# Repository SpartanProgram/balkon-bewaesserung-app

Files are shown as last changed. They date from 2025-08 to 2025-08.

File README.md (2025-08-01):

# 🌱 Balkon Bewässerung / Balcony Irrigation – Mobile App

*Automatisiertes Pflanzenbewässerungssystem mit Flutter, MQTT & ESP32*  

*A smart IoT plant watering system using Flutter, MQTT & ESP32*

---

## 📱 Funktionen / Features

### ✅ Echtzeitdaten / Live Monitoring  
- 🌿 Feuchtigkeitsanzeige (bis zu 3 Sensoren, einzeln dargestellt)  
- 💧 Anzeige des Wasserstands in % (Sensor 4)  
- 📊 Verlaufsgrafik der letzten 24 Stunden je Pflanze

---

- 🌿 Real-time moisture display (up to 3 individual sensors)  
- 💧 Water tank level display (Sensor 4)  
- 📊 Historical moisture charts (last 24h per plant)

### ✅ Steuerung / Smart Controls 
- 🚿 Manuelle Bewässerung (einzeln oder alle Pflanzen auf Knopfdruck)  
- ⏰ Zeitplan: automatische Bewässerung zu bestimmter Uhrzeit  
- 🔁 Gießdauer: 1–60 Sekunden einstellbar  
- 🔌 MQTT-Kommunikation mit dem ESP32  
- ✅ Steuerung mehrerer Pumpen

---

- 🚿 Manual watering (individual or all plants)  
- ⏰ Scheduled automatic watering (customizable time)  
- 🔁 Adjustable watering duration (1–60 seconds)  
- 🔌 MQTT communication with ESP32 microcontroller  
- ✅ Multiple pump control with per-plant logic

### ✅ Benachrichtigungen / Notifications  
- 🛎 Push-Benachrichtigungen bei:
  - ⚠️ Niedriger Feuchtigkeitswert (20%, 10%, 0%)  
  - 💧 Niedriger Wasserstand (< 20%)  
  - 🚱 Kein Wasser mehr (0%)  
  - 🚿 Automatische Bewässerung gestartet  
- 🟢 In-App-Warnungen mit Dialogfenster bei kritischen Zuständen

---

- 🛎 Push notifications for:
  - ⚠️ Low soil moisture (20%, 10%, 0%)
  - 💧 Low water tank level (< 20%)
  - 🚱 Water tank empty (0%)
  - 🚿 Automatic watering triggered  
- 🟢 In-app alert dialogs when thresholds are reached

### ✅ Speicherfunktionen / Persistence 
- 💾 Speicherung von „Letzte Bewässerung“ (bleibt auch nach App-Neustart erhalten)  
- 🕓 Speichern und Wiederherstellen des Zeitplans  
- 🧠 Verlaufshistorie der Sensorwerte (lokal gespeichert über 24h)  
- ⚙️ Shared Preferences für alle Einstellungen

---

- 💾 Last watering time per plant (saved across app restarts)  
- 🕓 Schedule is stored and automatically reloaded  
- 🧠 Sensor history (local 24h storage)  
- ⚙️ Uses Shared Preferences for all user settings

---

### Voraussetzungen / Requirements

- ✅ Flutter SDK (3.x)  
- ✅ Ein MQTT-Broker (z. B. Mosquitto, HiveMQ)  
- ✅ ESP32 mit Firmware zur MQTT-Kommunikation  
- 📱 iOS & Android-Unterstützung  

## 🚀 Installation & Ausführen / Getting Started

### 1. Projekt klonen / Clone the project

```bash
git clone https://github.com/your-username/bewaesserung-mobile-app.git
cd bewaesserung-mobile-app
flutter pub get
```

### 2. App starten / Run the app

```bash
flutter run
```

Hinweis: MQTT-Verbindung muss über die App-Einstellungen eingerichtet werden.

## ⚙️  MQTT Kommunikation / MQTT Integration

### 📥 Empfang /  Incoming Data (ESP → App)
Topic: pflanzen/pflanze01

```bash
{
  "sensor1": 55,
  "sensor2": 43,
  "sensor3": 87,
  "sensor4": 18,
  "pump": [false, false, false]
}
```

### 📤 Steuerung / Outgoing Control (App → ESP)
Topic: pflanzen/pflanze01/control

```bash
{
  "pump": [true, false, true],
  "duration": 15000
}
```

pump: Liste mit 3 Booleans für jede Pflanze / List of 3 booleans (one per plant)

duration: Dauer in Millisekunden (z. B. 15000 = 15 Sekunden) / Watering duration in milliseconds (e.g., 15000 = 15 seconds)

## 🧪 ESP Setup

Beim ersten Start: / On first setup:

Stecke die Sensoren kurz in trockene und feuchte Erde (für Kalibrierung)

Falls Feuchtigkeit nicht korrekt erkannt wird:

  Erstelle eine reset.txt auf dem ESP

  Lade die Firmware erneut hoch

---

Place the moisture sensors briefly in dry and wet soil for calibration

If readings appear inaccurate:

Create a reset.txt file on the ESP

Upload the firmware again to trigger sensor reset

## 🔐 Berechtigungen / Permissions

POST_NOTIFICATIONS (Android)

Lokale Benachrichtigungen (iOS & Android)

## 🛠 Verwendete Technologien / Tech Stack

Flutter

Provider (State Management)

mqtt_client

shared_preferences

flutter_local_notifications

Cupertino Widgets (iOS-Style Picker)

JSON-basiertes Datenmodell

## 👥 Team

👨‍💻 Zul Fahmi Nur Vagala – App-Entwicklung / Mobile App (Flutter)

🔌 Dzaid Abiyyu Siregar – ESP32-Entwicklung / ESP32 Firmware(Firmware)

🛠 Johannes Berg – Mechanik & Hardware / Mechanical Design & Hardware Integration

## 🧠 Projektziel / Project Scope

Dieses Projekt entstand im Rahmen des Fachprojekts (SoSe 2025) an der HTW Berlin und verfolgt das Ziel, ein günstiges, modulares und einfach bedienbares IoT-Bewässerungssystem zu entwickeln, das lokal und sicher arbeitet.

---

This project was developed as part of a student project (Summer Semester 2025) at HTW Berlin.
It aims to provide a smart, affordable, and locally controlled irrigation system for small balcony gardens.

## 📝 Lizenz / License

Dieses Projekt ist Teil des Fachprojekts an der HTW Berlin.
Nur für Studien- & Forschungszwecke freigegeben.

MIT License (bei öffentlicher Veröffentlichung)

---

This project is intended for educational and research use only.
Not licensed for commercial distribution.

MIT License (if publicly released)

## 📸 Screenshots 










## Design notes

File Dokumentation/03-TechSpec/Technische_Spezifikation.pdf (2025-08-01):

Technische Spezifikation
Automatische Balkonbewässerung
Ó htw-Berlin | Seite 1 von 16

# Technische Spezifikation

# Automatische Balkonbewässerung

Autor: | Mohammad Abuosba
Letzte Änderung: 13. Juni 2025
Dateiname: | Automatische_Balkonbewässerung_technische_Spezifikation
Version: | 1

## Inhaltsverzeichnis

## Abbildungsverzeichnis

Copyright

Ó Mohammad Abuosba

Die Weitergabe, Vervielfältigung oder anderweitige Nutzung dieses Dokumentes oder Teile davon ist unabhängig vom Zweck oder in welcher Form untersagt, es sei denn, die Rechteinhaber/In hat ihre ausdrückliche schriftliche Genehmigung erteilt.

## 1 Vorhandene Dokumente

Alle für die vorliegende Spezifikation ergänzenden Unterlagen müssen hier aufgeführt werden

Dokument | Autor | Datum
Last_Lastenheft.pdf | Dzaid, Johannes, Zul | 25.04.2025
Automatische_Balkonbewässerung_Pflichtenheft.pdf | Dzaid, Johannes, Zul | 23.05.2025

## 2 Prozessüberblick

## 2.1 Fachlicher Workflow

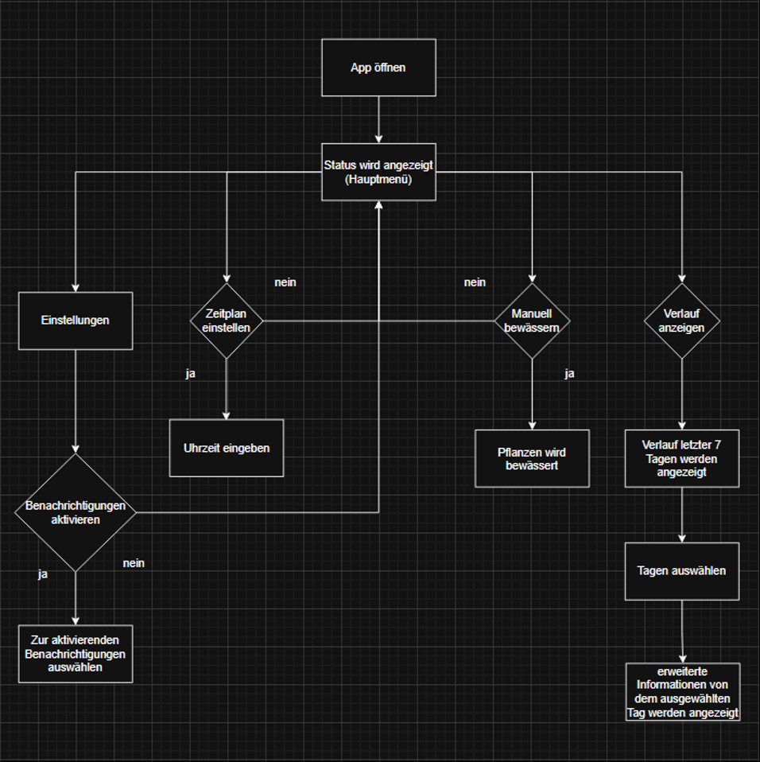
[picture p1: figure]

Abbildung 1: Fachlicher Workflow

Ablaufschema z.B.:

- Nutzer öffnet App → Dashboard → Navigation zu Verlauf/Zeitplan
- Manuelle/Automatische Bewässerung starten
- Ereignisse werden pro Wochentag gespeichert

## 2.2 Technischer Workflow

### 2.2.1 Sensor misst Spannung (analog) → ESP32

- Der Bodenfeuchtesensor liefert ein analoges Spannungssignal.
- Der ESP32 liest über einen ADC-Pin regelmäßig den Wert (z. B. alle 30 Sekunden).

### 2.2.2 ESP32 berechnet Feuchtigkeitswert

- Der ADC-Wert wird kalibriert und in einen Prozentwert (0–100 %) umgerechnet.

### 2.2.3 MQTT Publish

- Der ESP32 veröffentlicht den Feuchtigkeitswert an den Broker auf dem Topic:

### 2.2.4 App abonniert auf MQTT-Topic

- Die App ist mit demselben Broker verbunden und erhält die Sensordaten.
- Die UI zeigt den aktuellen Zustand

### 2.2.5 Automatische Entscheidung auf ESP

- Der ESP prüft lokal: Wenn value < threshold dann: GPIO High (Pumpe aktivieren)
- Alternativ: Prüfung gegen Zeitplan

### 2.2.6 Manuelle Steuerung über App

- Die App sendet MQTT-Befehl an
- “Jetzt Bewässern”

### 2.2.7 ESP abonniert auf Steuer-Topic

- Wenn Nachricht empfangen, GPIO High (Pumpe aktivieren wie eingestellt)

### 2.2.8 MQTT Logging

- Jede Aktion (Start, Stoppt, Fehler) wird an einem bestimmten Topic publiziert.

### 2.2.9 Fehlerhandling

- Wenn Sensor nicht lesbar (invalid), Fehlermeldung über MQTT publizieren
- App zeigt Fehlermeldung an

## 3 Technische Spezifikation SW 3.1 Überblick Komponenten

IT-Komponente | Funktion aus Pflichtenheft
Navigation | Drawer mit Seiten: Hauptmenü, Verlauf, Zeitplan
Verlauf | Anzeige pro Tag mit Icons und Dialog
Zeitplan | Zeitauswahl mit Schalter für automatische Bewässerung
Manuelle Steuerung | „Jetzt bewässern“-Button
UI-Komponenten | CustomScaffold, Popup-Dialoge

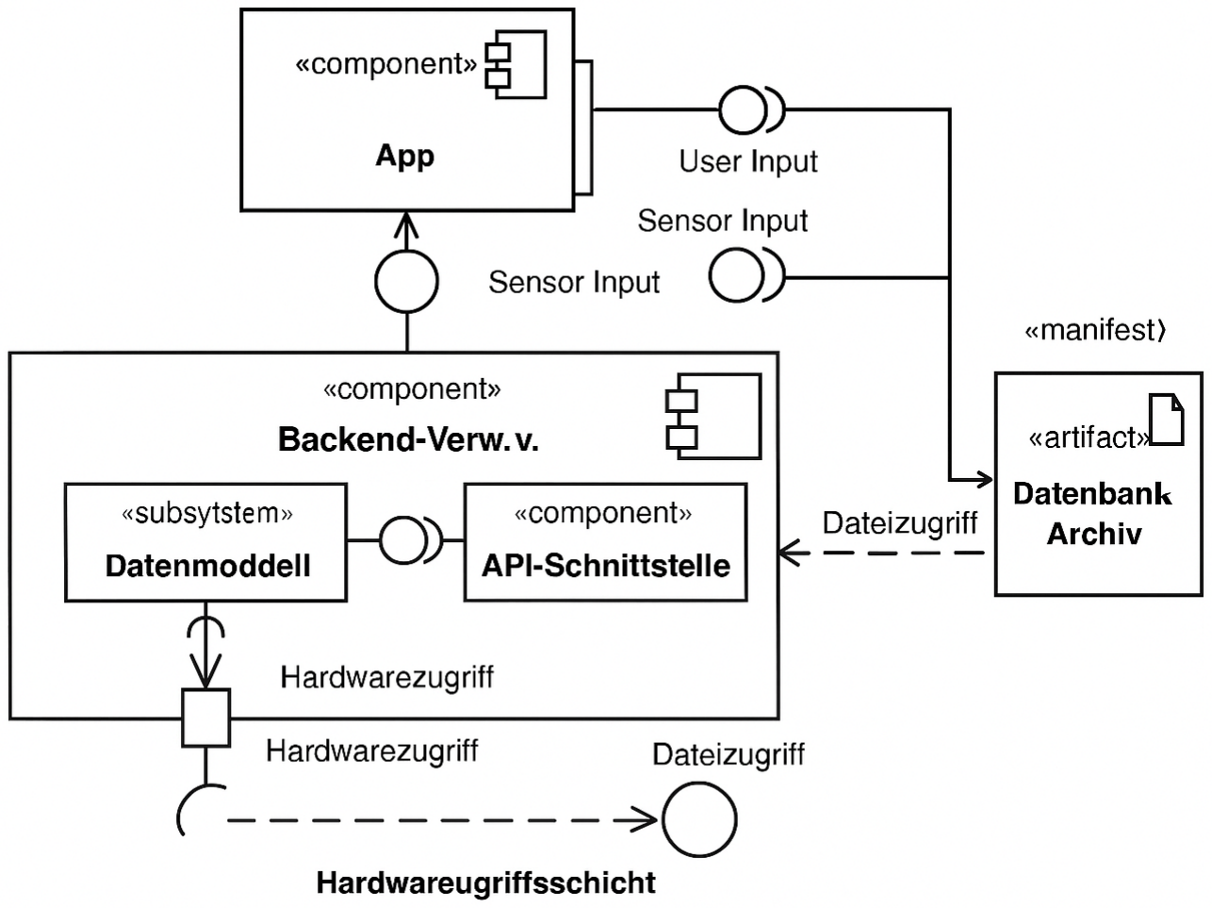
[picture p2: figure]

Abbildung 2: Komponentendiagramm

## 3.2 Beschreibung der Implementierung

## 3.2.1 Funktion 1: Zeitplan einstellen

# | Komponentendetail | Erforderliche Arbeiten

T1 | GUI | Flutter ZeitplanScreen, Switch & TimePicker
T2 | Logik | State Management (setState), Zeit speichern
T3 | Unterfunktion | _selectTime() – öffnet Zeitwahl

T1: GUI

Was wird implementiert?

- Startbildschirm mit aktuellem Sensorstatus
- Navigation durch mehrere Sensoren via PageView
- „Jetzt bewässern“-Button

Elemente:

- Überschrift (Text)
- Menü-Button ☰ für Drawer
- Sensoranzeige in Slideshow
- Indikatoren (● ○ ○)
- Bewässerungsbutton (ElevatedButton)

Verwendete Widgets/Bibliotheken:

- PageView.builder
- ElevatedButton
- Text, Row, Column, Spacer
- Icons, Material3, AnimatedPositioned

Interaktionen:

- Swipe → Sensor wechseln
- Klick auf Menü → Drawer mit Seiten

Fehlerbehandlung:

- Sensorwerte = null → Anzeige: „Daten nicht verfügbar“
- Kein Sensor → leerer Zustand mit Hinweis

T2: Logik

Ablauflogik:

- Beim Öffnen der App werden die Sensordaten geladen (lokal oder via API).
- Bei Wechsel der PageView wird der aktuelle Index gespeichert.
- Daten werden als List<Map<String, String>> verwaltet.

Pseudocode:

PageView.builder(
itemCount: sensors.length, onPageChanged: (i) => _currentIndex = i; )

State Management:

- StatefulWidget mit setState

Fehlerfälle:

- Ungültiger Wert → Farbliche Markierung (z. B. rot < 20 % Feuchtigkeit)

T3: Unterfunktion: “Jetzt bewäsern”

GUI:
- Grüner Button, abgerundet
- Auf voller Breite, mittig

Funktionalität:

- Sendet manuellen Befehl zur Bewässerung (z. B. POST an API)
- Feedback via Snackbar oder Animation

Pseudocode:

onPressed: () {
sendWateringCommand();
showSnackbar("Wasser gesendet"); }

Fehlerfälle:

Keine Verbindung → Snackbar mit „Fehler beim Senden“

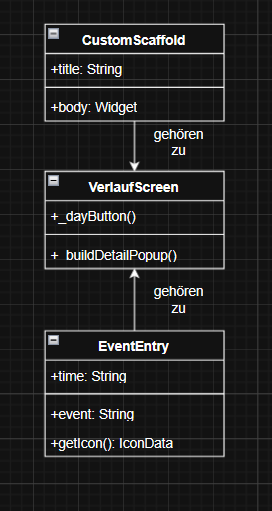
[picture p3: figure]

Abbildung 3: Klassendiagramm Zeitplan

## 3.2.2 Funktion 2: Verlauf anzeigen

# | Komponentendetail | Erforderliche Arbeiten

T4 | GUI | VerlaufScreen mit Buttons je Wochentag
T5 | Dialoge | Tagesbezogene Detaildialoge mit Icons
T6 | Animation | Übergangsanimation zwischen Tagen
T7 | Datenmodell | Map<String, List<Map<String, String>>> für Events

T4: GUI & Dialoge

- Verlauf-Bildschirm mit 7 Wochentags-Buttons
- Jeder Button öffnet Dialog mit Eventverlauf
- Icons je nach Ereignistyp

Elemente im Dialog:

- Titel: „Samstag – 29. April“
- Liste von Events mit Uhrzeit, Icon & Beschreibung
- Schließen-Button (oben links)

Widgets:

- Wrap, GestureDetector, Dialog
- ListView, Icon, Text, Row

T5: Animation

- showDialog nutzt Fade-In
- Neu: animierter Übergang zwischen Tagen (AnimatedSwitcher oder FadeTransition)

Fehlerbehandlung:
Kein Eintrag → „Keine Einträge für diesen Tag“
Formatfehler → Standard-Icon und grauer Text

T6: Datenmodell

Modell für Events:

{
"time": "11:00",
"event": "Automatisch bewässert (100 ml)"
}

Tabelle:
Feld | Typ | Beschreibung
time | String | Uhrzeit im HH.mm-Format
event | String | Bschreibung mit Kontext
type | Enum | (intern): moisture, water, error…

Zuordnung Icon/Typ:
- Feuchtigkeit → 💧 Icons.opacity
- Wasserstand → 🚰 Icons.water_drop
- Fehler → ⚠ Icons.error_outline

Logik zur Erkennung:

if (event.contains("bewässert")) => Icons.water
else if (event.contains("Fehler")) => Icons.error_outline

Animation (zwischen Tagen im Dialog):

AnimatedSwitcher(
duration: Duration(milliseconds: 300), child: EventListWidget(day),
)

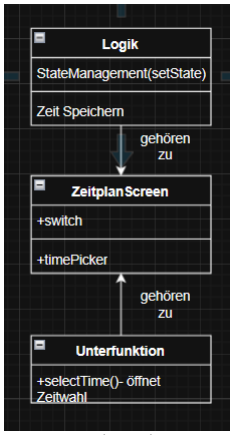
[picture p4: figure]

Abbildung 4: Klassendiagramm Verlauf

## 3.3 System Infrastruktur

- Plattform: Flutter (iOS, Android)
- Lokale Tests mit: iPhone Simulator, Android Emulator
- API-Kommunikation: (Wenn vorhanden, z. B. REST oder MQTT)
- App benötigt Netzwerkzugang
- Code verwaltet via GitLab Repository

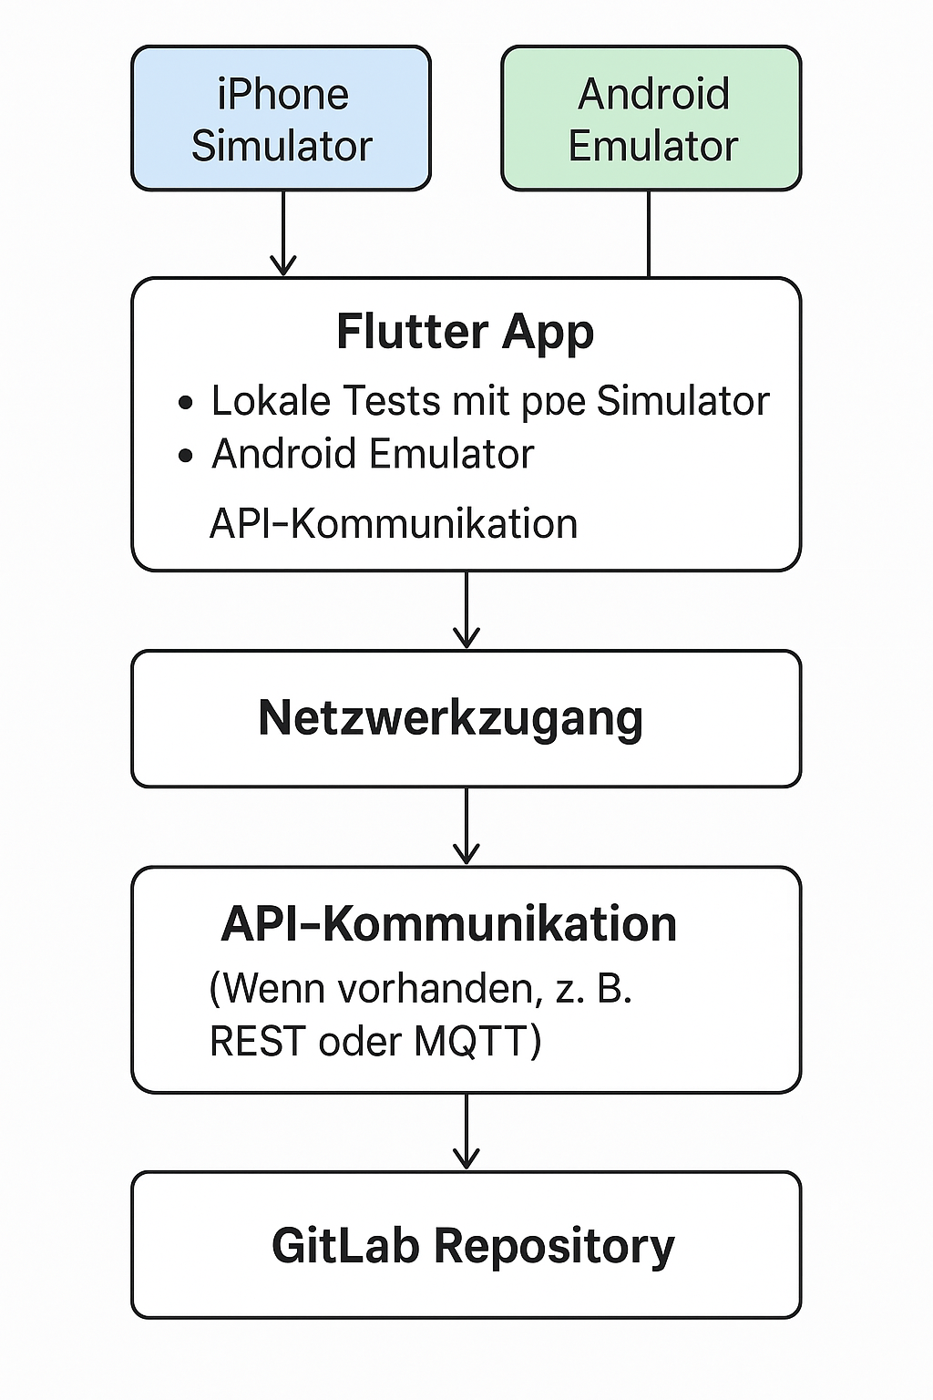
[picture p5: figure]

Abbildung 5: Systeminfrastruktur

## 4 Technische Spezifikation Konstruktion 4.1 Baugruppen

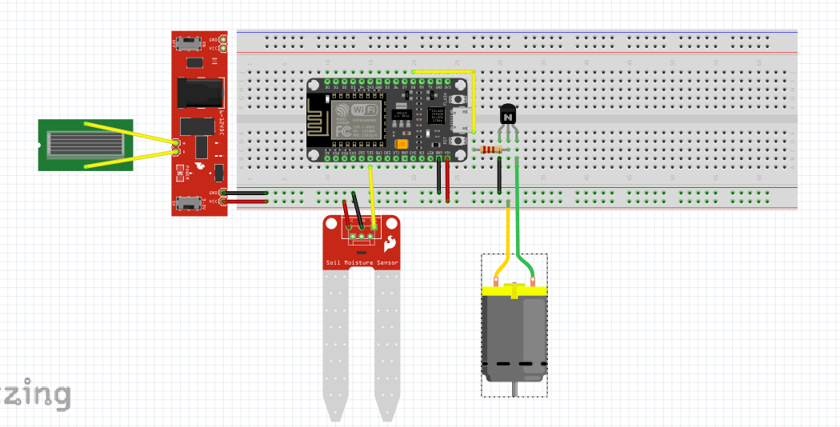
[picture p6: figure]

Abbildung 6: Pinout des µCs
Die Baugruppen sollen in diesem Abschnitt detailliert beschrieben werden.
- Eine Baugruppe erhält einen eigenen Namen
- Bauteile, die in mehreren Ästen der Struktur vorkommen, werden mehrfach genannt
- Die Baugruppe beinhaltet
- Einzelteile
- Unterbaugruppen
- Bei der Strukturstückliste ist der gesamte Aufbau des Produkts erkenntlich
Bei der Baukastenstückliste werden Unterbaugruppen nicht weiter aufgegliedert, die Struktur ist nur einstufig

## 5 Modul Abhängigkeiten

- Flutter App ↔ Sensor-Hardware (ESP32)
- Flutter App ↔ Backend/Server (wenn vorhanden)
- Flutter App ↔ Plattformen (iOS, Android SDK)

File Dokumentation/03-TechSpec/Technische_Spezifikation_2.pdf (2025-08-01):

Ó htw-Berlin Seite 1 von 16

Technische Spezifikation
Automatische Balkonbewässerung

# Technische Spezifikation 2

# Automatische Balkonbewässerung

Autor: | Mohammad Abuosba
Letzte Änderung: 11. Juli 2025
Dateiname: Automatische_Balkonbewässerung_technische_Spezifikation

Version: | 1

## Inhaltsverzeichnis

## Abbildungsverzeichnis

## 1 Vorhandene Dokumente

Alle für die vorliegende Spezifikation ergänzenden Unterlagen müssen hier aufgeführt werden

Dokument | Autor | Datum
Last_Lastenheft.pdf | Dzaid, Johannes, Zul | 25.04.2025
Automatische_Balkonbewässerung_Pflichtenheft.pdf | Dzaid, Johannes, Zul | 23.05.2025
Technische_Spezifikation.pdf | Dzaid, Johannes, Zul | 13.06.2025

## 2 Prozessüberblick

## 2.1 Fachlicher Workflow


Abbildung 1: Fachlicher Workflow

Ablaufschema z.B.:

- Nutzer öffnet App → Dashboard → Navigation zu Verlauf/Zeitplan
- Manuelle/Automatische Bewässerung starten
- Ereignisse werden pro Wochentag gespeichert

## 2.2 Technischer Workflow

### 2.2.1 Sensor misst Spannung (analog) → ESP32

- Der Bodenfeuchtesensor liefert ein analoges Spannungssignal.
- Der ESP32 liest über einen ADC-Pin regelmäßig den Wert (z. B. alle 30 Sekunden).

### 2.2.2 ESP32 berechnet Feuchtigkeitswert

- Der ADC-Wert wird kalibriert und in einen Prozentwert (0–100 %) umgerechnet.

### 2.2.3 MQTT Publish

- Der ESP32 veröffentlicht den Feuchtigkeitswert an den Broker auf dem Topic:

### 2.2.4 App abonniert auf MQTT-Topic

- Die App ist mit demselben Broker verbunden und erhält die Sensordaten.
- Die UI zeigt den aktuellen Zustand

### 2.2.5 Automatische Entscheidung auf ESP

- Der ESP prüft lokal: Wenn value < threshold dann: GPIO High (Pumpe aktivieren)
- Alternativ: Prüfung gegen Zeitplan

### 2.2.6 Manuelle Steuerung über App

- Die App sendet MQTT-Befehl an
- “Jetzt Bewässern”

### 2.2.7 ESP abonniert auf Steuer-Topic

- Wenn Nachricht empfangen, GPIO High (Pumpe aktivieren wie eingestellt)

### 2.2.8 MQTT Logging

- Jede Aktion (Start, Stoppt, Fehler) wird an einem bestimmten Topic publiziert.

### 2.2.9 Fehlerhandling

- Wenn Sensor nicht lesbar (invalid), Fehlermeldung über MQTT publizieren
- App zeigt Fehlermeldung an

## 3 Technische Spezifikation SW 3.1 Überblick Komponenten

IT-Komponente | Funktion aus Pflichtenheft
Navigation | Drawer mit Seiten: Hauptmenü, Verlauf, Zeitplan
Verlauf | Anzeige pro Tag mit Icons und Dialog
Zeitplan | Zeitauswahl mit Schalter für automatische Bewässerung
Manuelle Steuerung | „Jetzt bewässern“-Button
UI-Komponenten | CustomScaffold, Popup-Dialoge

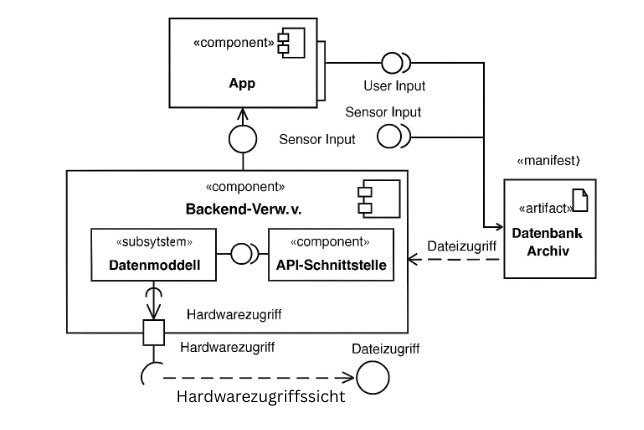
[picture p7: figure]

Abbildung 2: Komponentendiagramm

## 3.2 Beschreibung der Implementierung

## 3.2.1 Funktion 1: Zeitplan einstellen

# | Komponentendetail | Erforderliche Arbeiten

T1 | GUI | Flutter ZeitplanScreen, Switch & TimePicker
T2 | Logik | State Management (setState), Zeit speichern
T3 | Unterfunktion | _selectTime() – öffnet Zeitwahl

T1: GUI

Was wird implementiert?

- Startbildschirm mit aktuellem Sensorstatus
- Navigation durch mehrere Sensoren via PageView
- „Jetzt bewässern“-Button

Elemente:

- Überschrift (Text)
- Menü-Button ☰ für Drawer
- Sensoranzeige in Slideshow
- Indikatoren (● ○ ○)
- Bewässerungsbutton (ElevatedButton)

Verwendete Widgets/Bibliotheken:

- PageView.builder
- ElevatedButton
- Text, Row, Column, Spacer
- Icons, Material3, AnimatedPositioned

Interaktionen:

- Swipe → Sensor wechseln
- Klick auf Menü → Drawer mit Seiten

Fehlerbehandlung:

- Sensorwerte = null → Anzeige: „Daten nicht verfügbar“
- Kein Sensor → leerer Zustand mit Hinweis

T2: Logik

Ablauflogik:

- Beim Öffnen der App werden die Sensordaten geladen (lokal oder via API).
- Bei Wechsel der PageView wird der aktuelle Index gespeichert.
- Daten werden als List<Map<String, String>> verwaltet

Pseudocode:

PageView.builder(
itemCount: sensors.length, onPageChanged: (i) => _currentIndex = i; )

State Management:

- StatefulWidget mit setState

Fehlerfälle:

- Ungültiger Wert → Farbliche Markierung (z. B. rot < 20 % Feuchtigkeit)

T3: Unterfunktion: “Jetzt bewäsern”

GUI:
- Grüner Button, abgerundet
- Auf voller Breite, mittig

Funktionalität:

- Sendet manuellen Befehl zur Bewässerung (z. B. POST an API)
- Feedback via Snackbar oder Animation

Pseudocode:

onPressed: () {
sendWateringCommand();
showSnackbar("Wasser gesendet"); }

Fehlerfälle:

Keine Verbindung → Snackbar mit „Fehler beim Senden“

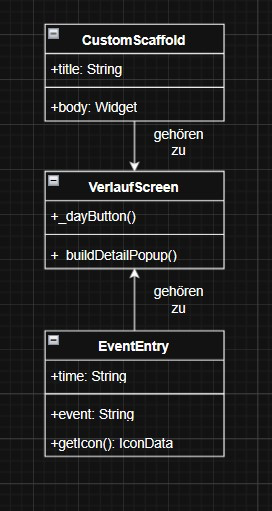
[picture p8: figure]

Abbildung 3: Klassendiagramm Zeitplan

## 3.2.2 Funktion 2: Verlauf anzeigen

# | Komponentendetail | Erforderliche Arbeiten

T4 | GUI | VerlaufScreen mit Buttons je Wochentag
T5 | Dialoge | Tagesbezogene Detaildialoge mit Icons
T6 | Animation | Übergangsanimation zwischen Tagen
T7 | Datenmodell | Map<String, List<Map<String, String>>> für Events

T4: GUI & Dialoge

- Verlauf-Bildschirm mit 7 Wochentags-Buttons
- Jeder Button öffnet Dialog mit Eventverlauf
- Icons je nach Ereignistyp

Elemente im Dialog:

- Titel: „Samstag – 29. April“
- Liste von Events mit Uhrzeit, Icon & Beschreibung
- Schließen-Button (oben links)

Widgets:

- Wrap, GestureDetector, Dialog
- ListView, Icon, Text, Row

T5: Animation

- showDialog nutzt Fade-In
- Neu: animierter Übergang zwischen Tagen (AnimatedSwitcher oder FadeTransition)

Fehlerbehandlung:
Kein Eintrag → „Keine Einträge für diesen Tag“
Formatfehler → Standard-Icon und grauer Text

T6: Datenmodell

Modell für Events:

{
"time": "11:00",
"event": "Automatisch bewässert (100 ml)"
}
Tabelle:
Feld | Typ | Beschreibung
time | String | Uhrzeit im HH.mm-Format
event | String | Bschreibung mit Kontext
type | Enum | (intern): moisture, water, error…

Zuordnung Icon/Typ:
- Feuchtigkeit → 💧 Icons.opacity
- Wasserstand → 🚰 Icons.water_drop
- Fehler → ⚠ Icons.error_outline

Logik zur Erkennung:

if (event.contains("bewässert")) => Icons.water
else if (event.contains("Fehler")) => Icons.error_outline

Animation (zwischen Tagen im Dialog):

AnimatedSwitcher( duration: Duration(milliseconds: 300),
child: EventListWidget(day),
)

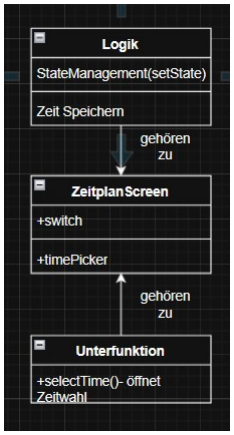
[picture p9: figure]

Abbildung 4: Klassendiagramm Verlauf

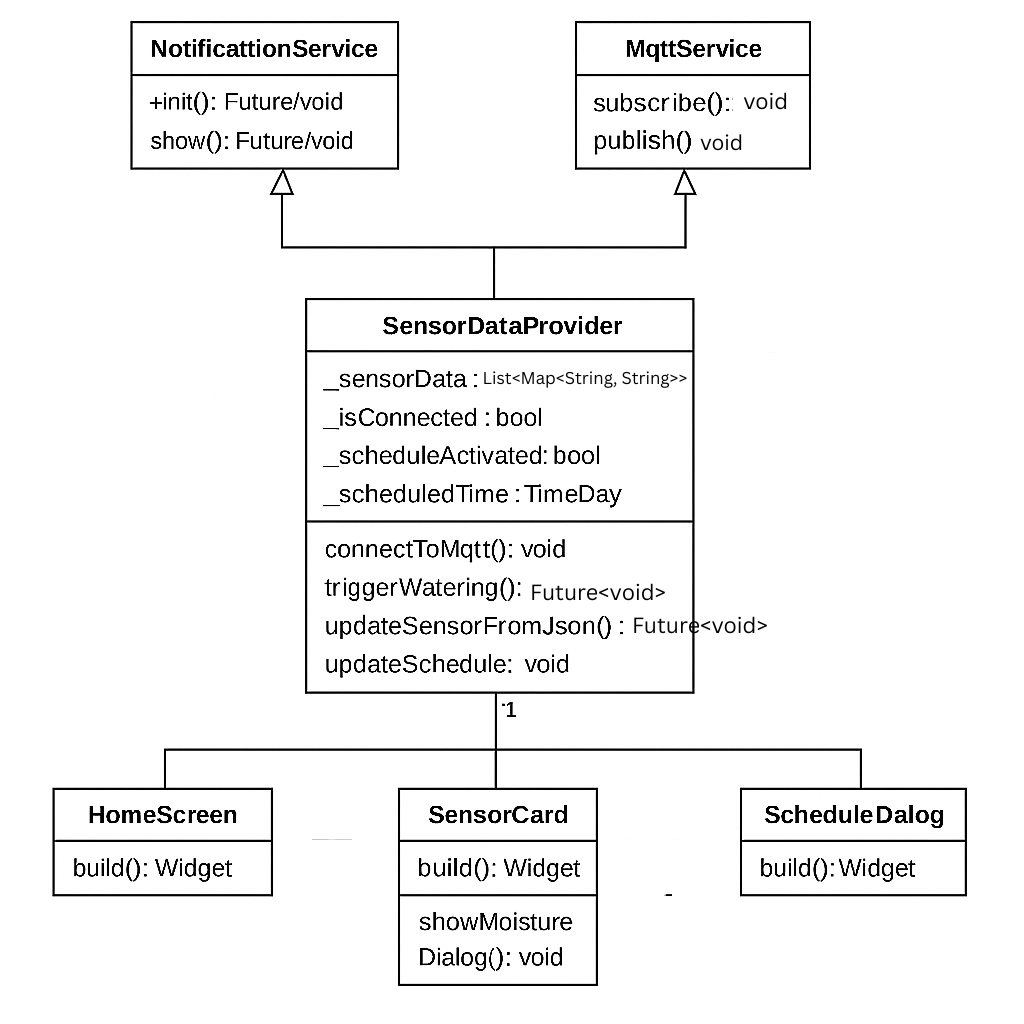
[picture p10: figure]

Abbildung 5:Klassendiagramm aller Systeme

## 3.3 System Infrastruktur

- Plattform: Flutter (iOS, Android)
- Lokale Tests mit: iPhone Simulator, Android Emulator
- API-Kommunikation: (Wenn vorhanden, z. B. REST oder MQTT)
- App benötigt Netzwerkzugang
- Code verwaltet via GitLab Repository

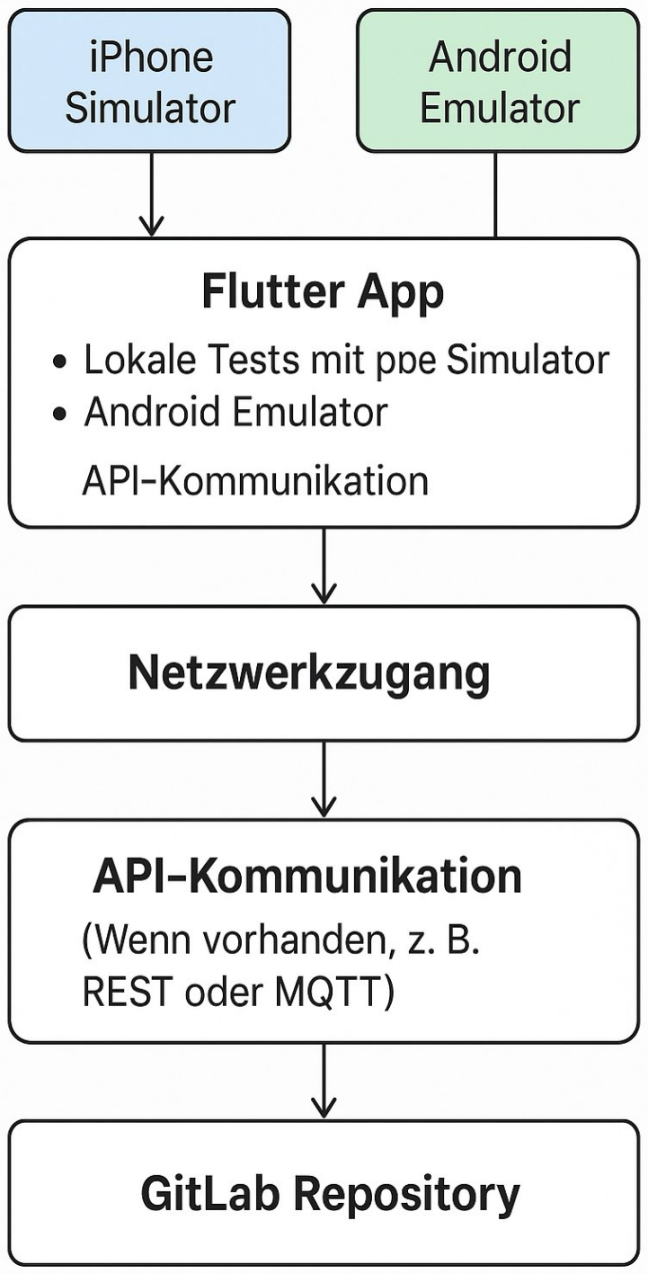
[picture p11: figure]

Abbildung 6: Systeminfrastruktur

## 3.4 Erweiterungen Sprint 2 – Software

In Sprint 2 wurden mehrere Funktionalitäten erweitert und neue Features hinzugefügt, um die Nutzbarkeit und Automatisierung der Balkonbewässerung zu verbessern.

## 3.4.1 Push-Benachrichtigungen (Flutter Local Notifications)

- Beschreibung: Die App benachrichtigt den Benutzer automatisch bei kritischen Ereignissen wie:
- 🌱 Niedrige Bodenfeuchtigkeit (unter 20 %)
- 💧 Niedriger Wasserstand (unter 20 %)
- 🌿 Automatische Bewässerung wurde durchgeführt
- Technologien: flutter_local_notifications, Android Notification Channels, iOS permission requests
- Benutzersteuerung:
- Ein Toggle in den Einstellungen ermöglicht das Aktivieren/Deaktivieren von Benachrichtigungen (Standard: aus)
- Speicherung der Benutzerauswahl via SharedPreferences

## 3.4.2 Hintergrundfunktionalität

- Funktion: Zeitplan-Bewässerung und MQTT-Kommunikation funktionieren auch, wenn die App im Hintergrund oder nicht geöffnet ist (sofern vom System erlaubt).
- Umsetzung:
- Timer.periodic in Kombination mit SharedPreferences zur Zeitplanprüfung
- MQTT bleibt verbunden, wenn loadAndConnectFromPrefs() erfolgreich war

## 3.4.3 MQTT-Verbindungseinstellungen

- Neue Features im Einstellungs-Screen:
- Felder für: Broker-Adresse, Port, Username, Passwort, TLS-Option
- Buttons:
- „🔌 Verbinden“
- „❌ Verbindung trennen“
- Link zum Erstellen eines MQTT-Accounts: HiveMQ Cloud (https://www.hivemq.com/mqtt-cloud-broker/)

## 3.4.4 Verlauf erweitert

- Beschreibung: Ereignisse wie niedrige Feuchtigkeit oder Wasserstand werden ebenfalls im Verlauf gespeichert.
- Darstellung: Neue Icons und Einträge für Warnungen
Ereignis | Icon | Beschreibung
Niedrige Feuchtigkeit | 🌱 | z.B. „Sensor 1: nur 18 %“
Niedriger Wasserstand | 💧 | z. B. „Wasserstand: 15 %“
Automatische Bewässerung | 🚿 | z. B. „Zeitplan: Sensor 2 bewässert“

## 3.4.5 Bugfixes & Optimierungen

- Echtzeitaktualisierung auf Android stabilisiert (z. B. reconnect bei Verbindungsabbruch)
- Fehlerbehandlung verbessert bei fehlerhafter Sensorübertragung (z. B. MQTT JSON Parsing)

## 4 Technische Spezifikation Konstruktion 4.1 Baugruppen

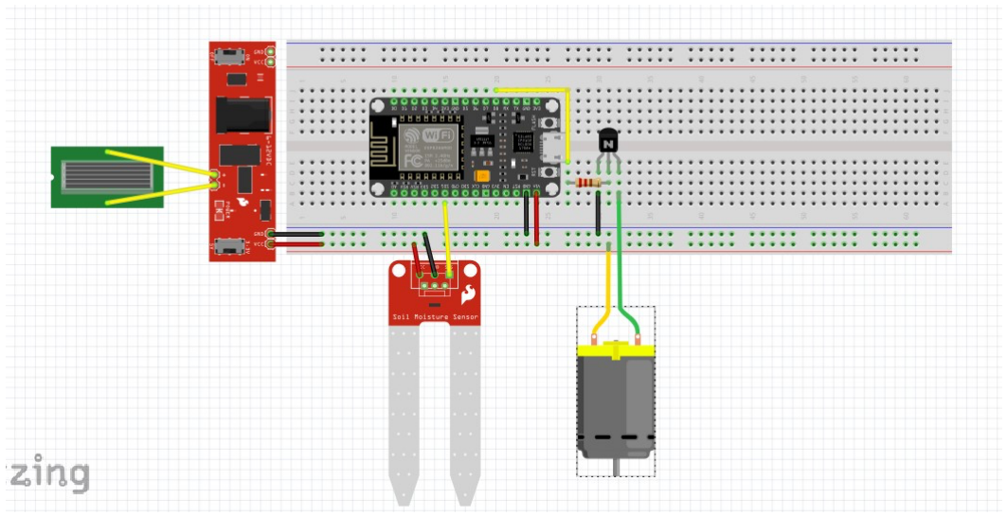
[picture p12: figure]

Abbildung 6: Pinout des µCs
Die Baugruppen sollen in diesem Abschnitt detailliert beschrieben werden.
- Eine Baugruppe erhält einen eigenen Namen o Bauteile, die in mehreren Ästen der Struktur vorkommen, werden mehrfach genannt
- | Die Baugruppe beinhaltet o | Einzelteile o | Unterbaugruppen
- Bei der Strukturstückliste ist der gesamte Aufbau des Produkts erkenntlich
Bei der Baukastenstückliste werden Unterbaugruppen nicht weiter aufgegliedert, die Struktur ist nur einstufig

## 5 Modul Abhängigkeiten

- Flutter App ↔ Sensor-Hardware (ESP32)
- Flutter App ↔ Backend/Server (wenn vorhanden)
- Flutter App ↔ Plattformen (iOS, Android SDK)

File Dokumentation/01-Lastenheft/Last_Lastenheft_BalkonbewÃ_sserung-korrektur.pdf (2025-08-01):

Lastenheft
Automatische Balkonbewässerung
Ó M. Abuosba, HTW Berlin | Seite 1 von 8

## Lastenheft

<Dennis Reinholz>
<Automatische Balkonbewässerung>
Autor: | Zul Vagala, Dzaid Siregar, Johannes Berg
Letzte Änderung: | 24.04.2025
Dateiname: | Automatische_Balkonbewässerung_Lastenheft
Version: | 3

## Inhaltsverzeichnis

Copyright

Ó Mohammad Abuosba

Die Weitergabe, Vervielfältigung oder anderweitige Nutzung dieses Dokumentes oder Teile davon ist unabhängig vom Zweck oder in welcher Form untersagt, es sei denn, die Rechteinhaber/In hat ihre ausdrückliche schriftliche Genehmigung erteilt.

Version Historie

Version: | Datum: | Verantwortlich
1 | 14.04.2025 | Dennis
2 | 16.04.2025 | Dzaid & Zul
3 | 24.10.2015 | Dennis & Zul

### 1 Einleitung

Pflanzen benötigen regelmäßige Pflege, insbesondere eine gleichmäßige und bedarfsgerechte Bewässerung. Viele Menschen haben jedoch im Alltag nicht immer die Zeit oder das nötige Wissen, um sich optimal um ihre Pflanzen zu kümmern. Genau hier setzt dieses Projekt an. Im Rahmen dieses Projekts wird ein automatisches Bewässerungssystem entwickelt, das mithilfe von Sensoren, einem Mikrocontroller und einer mobilen App arbeitet. Ziel ist es, eine intelligente Lösung zu schaffen, die den Feuchtigkeitsgehalt der Erde misst und die Pflanze bei Bedarf automatisch bewässert. Die Steuerung und Überwachung erfolgt bequem über das Smartphone.

### 2 Ausgangsituation

Zurzeit erfolgt die Bewässerung von Pflanzen in der Regel manuell. Dabei ist es oft schwierig, die optimale Wassermenge und den richtigen Zeitpunkt genau einzuhalten – besonders bei wechselnden Umweltbedingungen wie Temperatur oder Luftfeuchtigkeit. Ohne technische Unterstützung erfordert dies regelmäßige Aufmerksamkeit und kann im Alltag schnell vergessen werden. Ein automatisiertes System könnte hier für Entlastung sorgen und die Pflanzenpflege effizienter gestalten.

### 3 Zielsetzung

Das Ziel des Projekts ist es, ein kostengünstiges und einfach zu bedienendes System zu entwickeln, das die Pflanzenpflege automatisiert. Der Auftraggeber möchte eine Lösung, die zuverlässig erkennt, wann eine Pflanze Wasser benötigt, und diese dann automatisch bewässert. Dabei soll eine App dem Nutzer Informationen wie Bodenfeuchtigkeit, Temperatur und den aktuellen Zustand der Pflanze anzeigen. Langfristig soll das System den Alltag erleichtern und gleichzeitig einen Beitrag zur Nachhaltigkeit leisten, indem Wasser effizient eingesetzt wird.

### 4 Anforderungen 4.1 Funktionale Anforderungen 4.2 Konstruktive Anforderungen

Tabelle 1: | Konstruktive Anforderungen
Nr. Gruppe | Beschreibung | Priorität
1. | Feuchtigkeitssensoren | Das System muss kapazitive Bodenfeuchtesensoren verwenden, um den Feuchtigkeitsgehalt des Bodens präzise zu messen | Hoch
2. | Mikrocontroller | Ein ESP32-Mikrocontroller soll als zentrale Steuereinheit dienen, um Sensordaten zu verarbeiten und die Pumpe zu steuern | Hoch
3. | Bewässerungseinheit | Eine elektrisch gesteuerte Pumpe, die über ein Relaismodul vom ESP32 aktiviert wird, soll die Bewässerung durchführen. | Hoch
4. | Stromversorgung | Das System muss über eine stabile Stromquelle verfügen, entweder durch Netzstrom oder einen ausreichend dimensionierten Akku mit Solaranlage. | Hoch
5. | Network-Gateway | Das Gateway dient als Kommunikationsgerät zwischen dem ESP32 und das Internet | Mittel

### 4.3 Software-Anforderungen

Tabelle 2: | Software-Anforderungen
Nr. | Beschreibung | Priorität
1. | Die App zeigt den aktuellen Status der Bewässerung in Echtzeit an. | Hoch
2. Die Nutzer können die Bewässerung manuell über die App starten oder | stoppen. | Hoch
3. Die App soll automatisch Bewässerungszyklen basierend auf Sensorwerten | steuern. | Hoch
4. Fehler oder Warnungen sollen dem Nutzer per Push-Nachricht mitgeteilt | werden. | Hoch
5. Messdaten (z. B. Feuchtigkeit) sollen in der App in einer List dargestellt | werden. | Mittel
6. Die Software soll CI/CD-Pipelines für automatisierte Builds und Deployments | nutzen. | Mittel
7. | Die Kommunikation zwischen App und Microcontroller erfolgt über MQTT. | Niedrig
8. | Die App soll mehrere Benutzerprofile unterstützen können. | Niedrig

### 4.4 Technische Anforderungen

Tabelle 3: | Technische Anforderungen
Nr. | Gruppe | Beschreibung | Priorität
1. | Netzwerkverbindung | Der Mikrocontroller muss sich per WLAN mit einem lokalen Netzwerk oder Gateway verbinden können.
2. | MQTT-Kommunikation | Das System muss das MQTT-Protokoll zur Datenübertragung verwenden. Der Mikrocontroller (ESP32) fungiert als Publisher, die mobile Anwendung als Subscriber. Die MQTT-Kommunikation erfolgt über ein lokales oder cloudbasiertes Gateway.
3. | Datenformat | Alle übertragenen Daten sollen im JSON-Format codiert sein, um eine einheitliche, leicht interpretierbare Datenstruktur sicherzustellen.

### 4.5 Nicht-Funktionale Anforderungen

Tabelle 4: | Nicht-Funktionale Anforderungen
Nr. | Qualitätskriterien | Beschreibung | Priorität
1. Zuverlässigkeit
1.1 System muss nach einem Strom- oder | Netzwerkausfall automatisch wieder den Betrieb aufnehmen können | hoch
1.2 Sensorfehler oder Ausfälle einzelner Komponente | sollen erkannt und gemeldet werden. | hoch
2. Benutzbarkeit
2.1 Die App soll eine intuitive Benutzeroberfläche mit | hoch klaren Symbolen und verständlichen Anweisungen Bieten. | hoch
2.2 | Bedienung soll mit wenigen Klicks möglich sein. | hoch
3. Effizienz
3.1 | Das System soll energieeffizient arbeiten | mittel
3.2 Datenübertragung zwischen Controller und App | sollen auf ein Minimum beschränkt werden, um Ressourcen zu sparen | niedrig
4. Wartungsfreundlichkeit
4.1 Der Quellcode muss modular und nach Clean- | Code Prinzipien aufgebaut sein, um Wartung und Erweiterungen zu erleichtern. | hoch
4.2 Software soll durch automatische Tests | überprüfbar sein. | mittel
5. Übertragbarkeit
5.1 System soll leicht an verschiedene Pflanzenarten | und Balkonkonfigurationen anpassbar sein. | niedrig
5.2 App soll auf IOS und Android Geräten lauffähig sein, | ohne Änderungen am Quellcode. | hoch

### 4.6 Angestrebte Lösungsskizze (Modell)

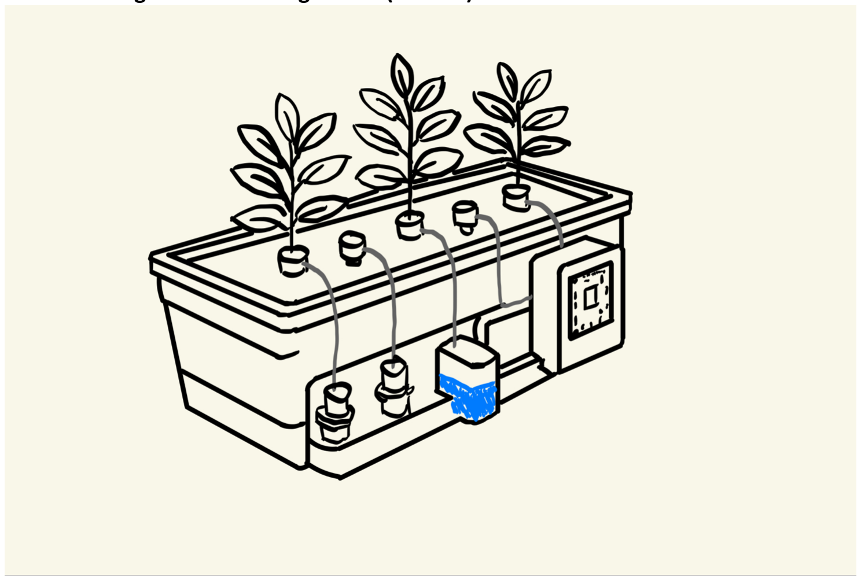
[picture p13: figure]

Abbildung 1: Modell

### 5 Abnahmekriterien

1. Die App muss den aktuellen Status der Bewässerung in Echtzeit anzeigen.
Das System gilt als abgenommen, wenn der Status der Bewässerung auf der Benutzeroberfläche automatisch aktualisiert wird.
2. Die manuelle Steuerung der Bewässerung über die App muss zuverlässig funktionieren.
Die Funktion gilt als erfüllt, wenn der Nutzer die Bewässerung über einen Button in der App starten und stoppen kann.
3. Die automatische Bewässerung muss zuverlässig anhand der Sensorwerte gesteuert werden. Dieses Kriterium ist erfüllt, wenn bei Unterschreitung eines voreingestellten Feuchtigkeitsgrenzwerts die Bewässerung automatisch startet und nach Erreichen des Sollwerts wieder endet.
4. Fehlerzustände oder Warnungen müssen dem Nutzer aktiv durch eine Push-Benachrichtigung mitgeteilt werden.
Das System wird akzeptiert, wenn es bei Ausfall eines Sensors oder bei leerem Wasserbehälter eine Benachrichtigung an den Nutzer innerhalb von 30 Sekunden versendet.
5. Die App muss auf iOS- und Android-Geräten mit einer intuitiven Benutzeroberfläche ausgestattet sein.
Die App gilt als abnahmefähig, wenn alle Kernfunktionen auf beiden Plattformen fehlerfrei funktionieren und mindestens 80 % der Testnutzer die Bedienbarkeit als „intuitiv“ bewerten.

### 6 Ansprechpartner für Rückfragen

Name | Mohammad Abuosba
Funktion | Projektleiter Auftraggeber
email | abuosba@htw-berlin.de
Telefon | +49 (30) 5019-3665

### 7 Wer hat was gemacht

Autor | Aufgabe/Kapitel | Anteil
Dzaid | Einleitung, Ausgangssituation, Zielsetzung Funktionale & Technische Anforderungen | 100% 50%
Zul | Abnahmekriterien Funktionale & Technische Anforderungen Lösungsskizze (GUI) | 100% 50% 50%
Johannes | Nicht-funktionale & konstruktive Anforderungen Lösungsskizze (Modell) | 100% 50%

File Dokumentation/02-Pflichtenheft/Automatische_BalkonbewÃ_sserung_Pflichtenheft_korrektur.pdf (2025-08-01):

Pflichtenheft
Automatische Balkonbewässerung
Ó htw-Berlin | Seite 1 von 23

# Pflichtenheft

# Automatische Balkonbewässerung

Autor: | Dzaid Abiyyu Siregar, Zul Fahmi Nur Vagala, Johannes Berg
Letzte Änderung: . 22 Mai 2025
Dateiname: | Pflichtenheft_Automatische_Balkonbewässerung.docx
Version: | 1.3

## Inhaltsverzeichnis

## Tabellenverzeichnis

## Abbildungsverzeichnis

Copyright

Ó Mohammad Abuosba

Die Weitergabe, Vervielfältigung oder anderweitige Nutzung dieses Dokumentes oder Teile davon ist unabhängig vom Zweck oder in welcher Form untersagt, es sei denn, die Rechteinhaber/In hat ihre ausdrückliche schriftliche Genehmigung erteilt.

Version Historie

Version: | Datum: | Verantwortlich | Änderung
1.0 | 16.05.2025 | Johannes Berg | Überblick, Ziele, Annahmen und Abgrenzungen
1.1 | 22.05.2025 | Zul Fahmi Nur Vagala | Funktionalität
1.2 | 22.05.2025 | Dzaid Abiyyu Siregar | Workflow & Funktionalität
1.3 | 23.05.2025 | Dzaid & Zul & Johannes | Abgabe

## 1 Vorhandene Dokumente

Tabelle 1: Vorhandene Dokumente
Dokument | Autor | Datum
Lastenheft | Dzaid Abiyyu Siregar, Zul Fahmi Nur Vagala, Johannes Berg | 25.04.2025

## 2 Überblick

Das Projekt „Automatische Bewässerung für Balkonpflanzen“ hat das Ziel, eine intelligente und kostengünstige Lösung zur automatisierten Pflanzenbewässerung zu entwickeln. Der Fokus liegt auf der Anwendung in einem Balkonumfeld, wobei mehrere Pflanzen in einem gemeinsamen Pflanzkasten untergebracht sind.

Das System erkennt mithilfe von Bodenfeuchtesensoren, wann die Pflanzen Wasser benötigen. Eine Steuereinheit (Microcontroller) wertet die Sensorwerte aus und aktiviert bei Bedarf eine Pumpe, um Wasser aus einem externen Behälter gezielt zu den Pflanzen zu leiten. Jede Pflanze kann individuell versorgt werden. Die Benutzer können über eine App den aktuellen Zustand der Pflanzen überwachen (z. B. Feuchtigkeitswerte) und grundlegende Einstellungen vornehmen.

Die gesamte Technik ist platzsparend im oder am Pflanzkasten untergebracht. Dabei wird darauf geachtet, dass Schläuche und Kabel ordentlich verlegt und ggf. verkleidet werden. Das System ist modular aufgebaut, sodass es zukünftig problemlos erweitert oder an andere Pflanzkästen angeschlossen werden kann.

Ziel ist es, die Pflanzenpflege zu erleichtern, den Wasserverbrauch zu optimieren und die Bedienung auch für technisch weniger erfahrene Nutzer möglichst einfach zu gestalten.

## 3 Hauptziele

Tabelle 2: Hauptziele
# | Ziel | Beschreibung der Implementation

1 | Automatisierte Bewässerung | Feuchtigkeitssensoren erkennen den Bedarf, Pumpen und Ventile reagieren automatisch
2 | Einfache Bedienung | Intuitive App-Oberfläche (siehe GUI-Skizze) für Android und IOS Einfache Inbetriebnahme und automatisierte Abläufe
3 | Kostengünstiges System | Verwendung günstiger Komponente, wie z.B. Microcontroller, einfache Sensoren und 3D-gedruckte Teile
4 | Zuverlässige Erkennung | Pro Pflanze ein Sensor zur genauen Feuchtigkeitsmessung
5 | Anzeige der Daten über App | Entwicklung einer App, um Zustandsdaten grafisch darzustellen
6 | Modularität und Erweiterbarkeit | Microcontroller erlaubt Anbindung weiterer Pflanzkästen oder Sensoren

## 4 Annahmen und Abgrenzungen

Tabelle 3: Annahmen und Abgrenzungen
# | Annahmen (fachliche und technische Annahmen)

1 | Nutzer hat Zugriff zu WLAN oder Bluetooth (App-Kommunikation)
2 | System wird in einem geschützten Außenbereich installiert
3 | Dauerhafte Stromversorgung (z.B. über USB (evtl. Solar))
4 | Pflanzen haben ähnlichen Wasserbedarf
5 | Nutzer befüllt Wasserbehälter regelmäßig (manuell)
# | Abgrenzungen (Was ist in dieser Lösung nicht enthalten bzw. abgedeckt)

1 | Gehäuse schützt vor Spritzwasser, aber nicht vor starkem Regen oder direktem UV-Licht
2 | Keine Düngung o.ä.
3 | System trifft Entscheidungen rein regelbasiert, keine Bilderkennung oder anderes KI-gestütztes Monitoring
4 | Keine autonome Wasserbefüllung
5 | App verfügt über keine Datenweiterleitung in z.B. Cloud

## 5 Workflow

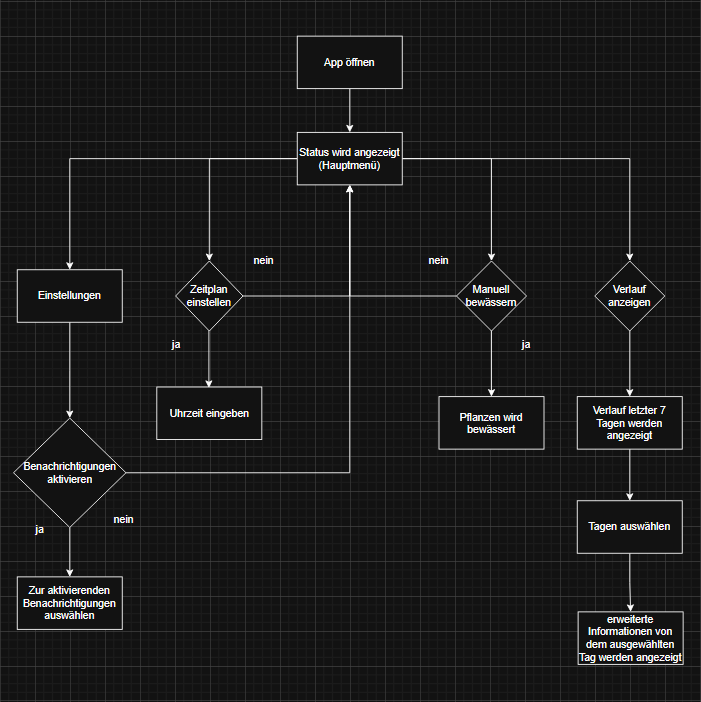
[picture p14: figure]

Abbildung 1: Workflow

## 6 Funktionalität 6.1 Überblick

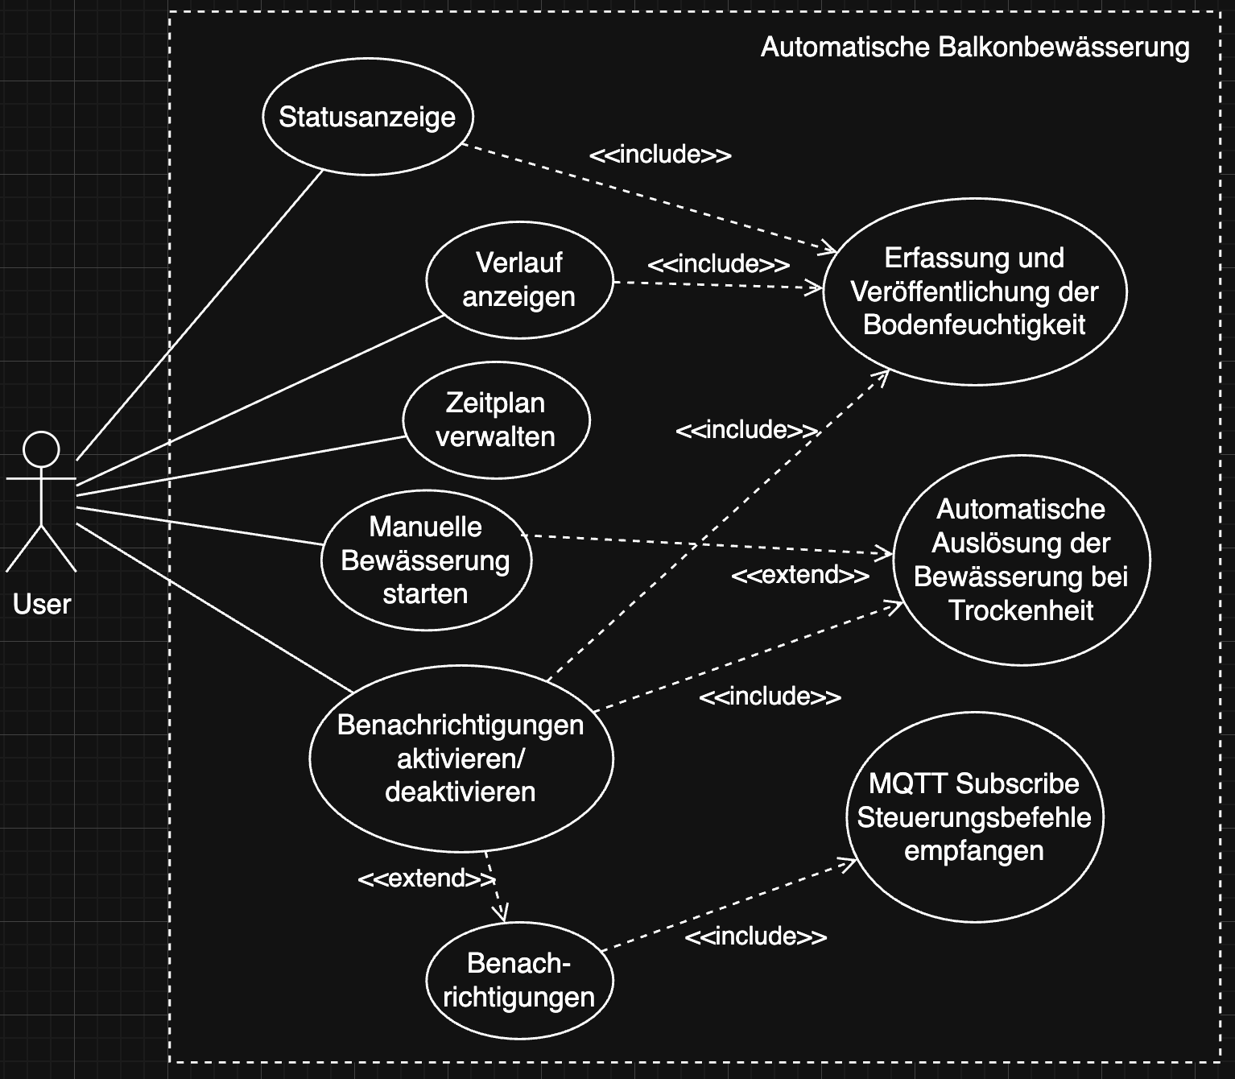
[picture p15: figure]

Abbildung 2: Use-Case-Diagramm

## 6.2 Statusanzeige

Tabelle 4: Statusanzeige
Zweck/Ziel | Anzeige von aktuellen Sensorwerten: Bodenfeuchtigkeit, Wasserstand, letzte Bewässerung.
Akteur/Auslöser | Benutzer beim Öffnen der App
Berechtigung | Keine Anmeldung nötig
Vorbedingung | 1. Sensorwerte müssen empfangbar sein
2. Verbindung zum Mikrocontroller besteht
Daten-Input | Werte der Sensoren (z. B. Bodenfeuchtigkeit: 45 %, Wasserstand: 75 %)
Verarbeitungsschritte | 1. App empfängt Sensorwerte vom Mikrocontroller
2. Werte werden visuell in der Startansicht angezeigt
Ergebnis | Live-Status der Pflanzenpflege ist sichtbar
Plausibilitäten | 1. Feuchtigkeit: 0–100 %
2. Wasserstand: 0–100 %
3. Letzte Bewässerung: heutiges Datum ≤ aktuelles Datum
Fehlerhandling | Bei fehlender Verbindung: Anzeige „Keine Verbindung“
Folgeprozess | 1. Möglichkeit zur manuellen Bewässerung 2. Trigger für automatische Benachrichtigung bei kritischen Werten
Out of Scope | 1. Historische Datenanalyse 2. GPS-/Standortinformationen
Test Cases | 1. Sensorwert < 10 % → Warnmeldung 2. Verbindung unterbrochen → Offline-Anzeige erscheint

## 6.3 Manuelle Bewässerung starten

Tabelle 5: Manuelle Bewässerung starten
Zweck/Ziel | Direktes Auslösen der Pumpe durch den Nutzer
Akteur/Auslöser | Benutzer klickt auf „Jetzt bewässern“
Berechtigung | Nutzer mit App-Zugriff
Vorbedingung | Verbindung zur Pumpe via Mikrocontroller
Daten-Input | Buttonklick + voreingestellte Menge (z. B. 150 ml)
Verarbeitungsschritte | 1. Klicksignal → Mikrocontroller
2. Pumpe wird aktiviert
3. Protokollierung im Verlauf
Ergebnis | Pumpe läuft und Pflanzen werden bewässert
Plausibilitäten | 1. Max. Menge: 300 ml 2. Mindestintervall: 30 Min. Abstand zwischen 2 Bewässerungen
Fehlerhandling | 1. Kein Wasser: Push-Benachrichtigung 2. Timeout: Hinweis „Pumpenfehler“
Folgeprozess | Eintrag im Verlauf, ggf. Statusaktualisierung
Out of Scope | 1. Teilweise Zonenbewässerung 2. Mengenregelung durch Benutzer
Test Cases | 1. Bewässerung erfolgreich → Protokolleintrag erscheint
2. Kein Wasser → App zeigt Warnmeldung

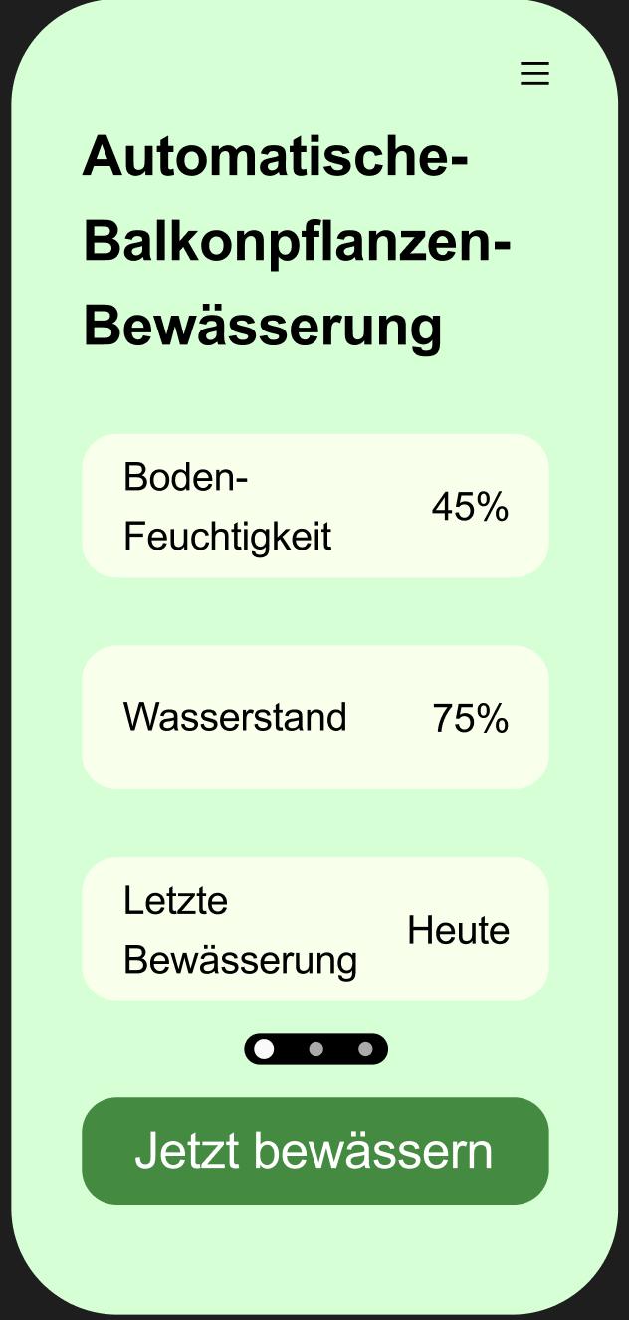
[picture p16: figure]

Abbildung 3: Hauptmenü

## 6.4 Verlauf anzeigen

Tabelle 6: Verlauf anzeigen
Zweck/Ziel | Tägliche Protokollierung von Sensorwerten und Aktionen
Akteur/Auslöser | Benutzer navigiert zu „Verlauf“
Berechtigung | Alle Benutzer
Vorbedingung | Mindestens 1 Eintrag im Verlauf vorhanden
Daten-Input | Tagesauswahl in den letzten 7 Tagen (Mo–So)
Verarbeitungsschritte | 1. Datenabruf aus interner Datenbank 2. Anzeige als Liste chronologisch
Ergebnis | Tagesansicht mit Ereignissen
Plausibilitäten | Einträge sortiert nach Zeit
Fehlerhandling | Keine Daten: Anzeige „Keine Ereignisse vorhanden“
Folgeprozess | ggf. Verweis auf die direkt folgenden Prozesse bzw. Funktionen im Workflow
Out of Scope | 1. Exportfunktion 2. Statistik oder Diagramm
Test Cases | 1. Klick auf Freitag → zeigt 5 Aktionen korrekt 2. Kein Eintrag → „Keine Daten“ wird angezeigt

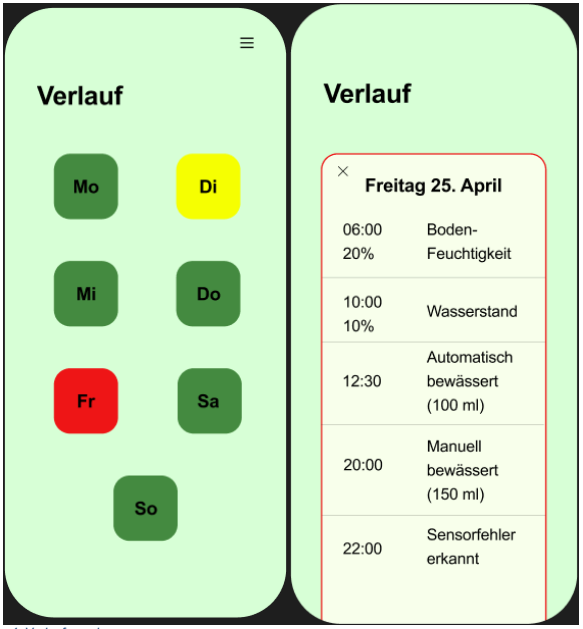
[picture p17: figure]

Abbildung 4: Verlauf anzeigen

Tabelle 7: Zeitplan verwalten

## 6.5 Zeitplan verwalten (als Backup)

Zweck/Ziel | Festlegen einer täglichen Uhrzeit für automatische Bewässerung
Akteur/Auslöser | Benutzer aktiviert Zeitfunktion
Berechtigung | Alle Benutzer
Vorbedingung | App ist mit System verbunden
Daten-Input | Uhrzeit (z. B. 08:00)
Verarbeitungsschritte | 1. Auswahlzeit in UI
2. Speicherung im Mikrocontroller
3. Auslösung zur definierten Zeit
Ergebnis | Bewässerung erfolgt automatisch zur festgelegten Uhrzeit
Plausibilitäten | 1. Gültige Uhrzeitformate (hh:mm)
2. Nur eine aktive Zeit erlaubt
Fehlerhandling | 1. Keine Speicherung möglich → Fehlermeldung
2. System nicht erreichbar → Warnung
Folgeprozess | Automatische Pumpe + Eintrag im Verlauf
Out of Scope | 1. Mehrere Zeiten 2. Wochenplan
Test Cases | 1. Zeit auf 08:00 gesetzt → Bewässerung erfolgt korrekt 2. Uhrzeit fehlerhaft → Speicherung verweigert

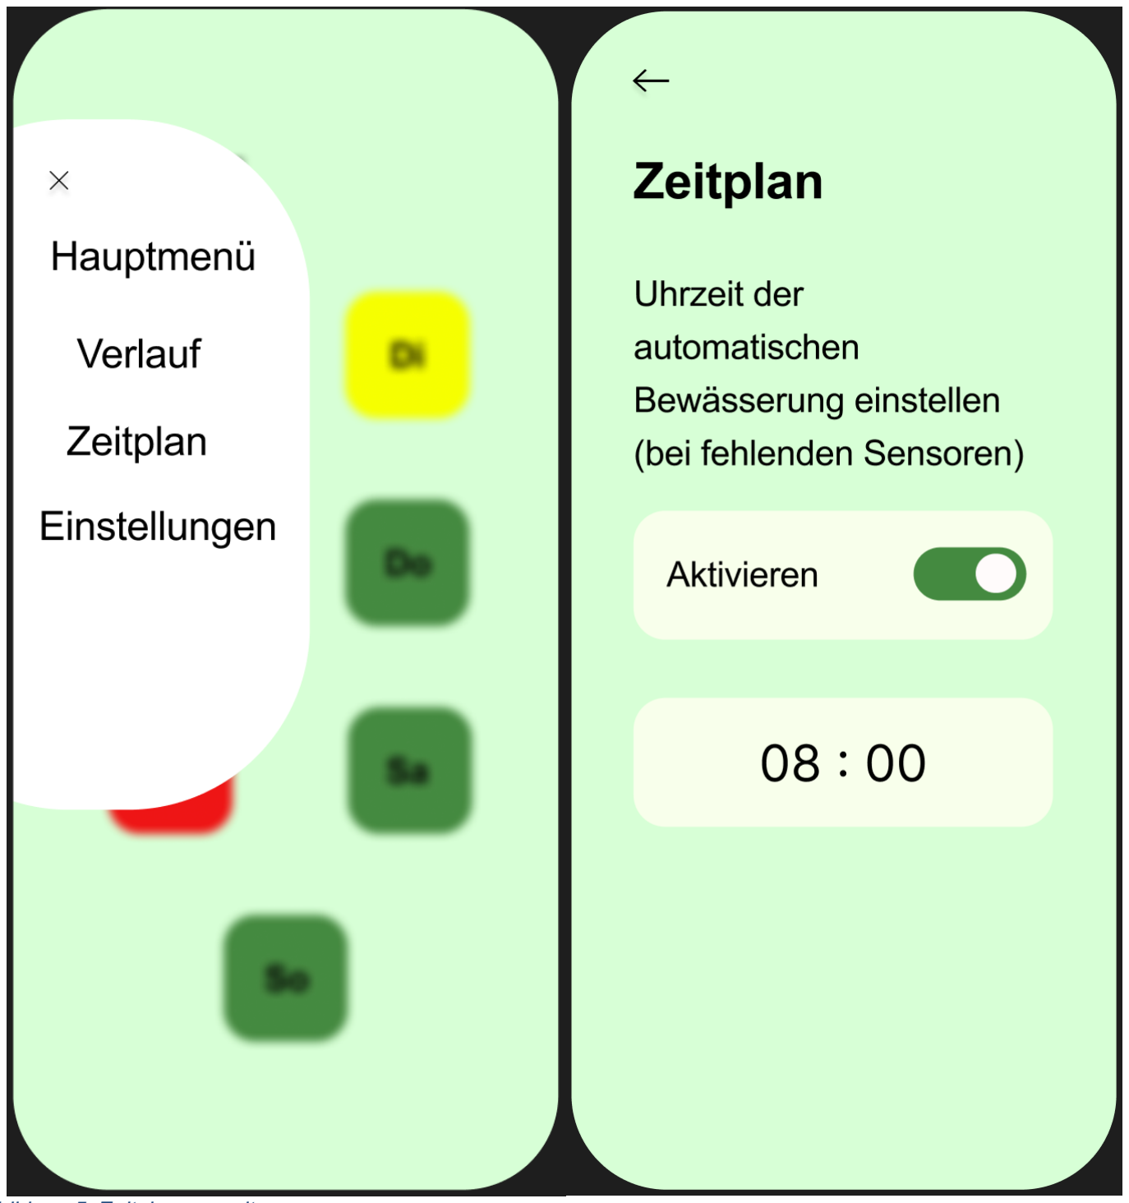
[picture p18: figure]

Abbildung 5: Zeitplan verwalten

## 6.6 Benachrichtigungen aktivieren/deaktivieren

Tabelle 8: Benachrichtigungen aktivieren/deaktivieren
Zweck/Ziel | Nutzer erhält Push-Nachrichten bei Ereignissen
Akteur/Auslöser | Benutzer schaltet Benachrichtigungen-Einstellung ein
Berechtigung | Alle Benutzer
Vorbedingung | 1. Benachrichtigungen sind im Gerät und in der App erlaubt 2. WLAN-/Bluetooth-Verbindung besteht (?)
Daten-Input | Fehlercodes, Sensordaten, Pumpenstatus
Verarbeitungsschritte | 1. Sensor meldet kritischen Zustand oder Systemereignis 2. Mikrocontroller analysiert Daten 3. Ereignis wird als Push-Nachricht übermittelt
Beanchrichtigungstypen | Kategorie: Nachricht (Beispieltext)
1. Feuchtigkeit: „Achtung! Bodenfeuchtigkeit unter 20 %. Gießen
| empfohlen.“
2. Wasserstand: „Wassertank fast leer. Bitte nachfüllen.“
3. Sensorfehler: „Fehler: Bodenfeuchtesensor nicht erreichbar.“
4. Pumpenfehler: „Warnung: Pumpe konnte nicht aktiviert werden.“
5. Automatische Aktion: „Automatische Bewässerung wurde um 08:00 Uhr
| erfolgreich durchgeführt.“
6. Manuelle Aktion: „Manuelle Bewässerung wurde ausgeführt (150 ml).“
7. System online/offline: „Verbindung zum Bewässerungssystem
| wiederhergestellt.“ oder „Verbindung verloren.“
Ergebnis | 1. Der Nutzer wird zeitnah über den Zustand des Systems informiert
2. Möglichkeit, über App oder manuell zu reagieren
Plausibilitäten | 1. Max. eine Benachrichtigung pro Ereignis alle 5 Minuten
2. Nur bei tatsächlichem Problem (z. B. Schwellenwert unterschritten)
Fehlerhandling | Push fehlgeschlagen → App zeigt Hinweis
Folgeprozess | Je nach Typ: Nutzer kann System prüfen, Wasser auffüllen, manuell starten etc.
Out of Scope | 1. E-Mail-Versand 2. Fehlerbehebung direkt in App
Test Cases | 1. Sensorwert < 20 % → Push-Benachrichtigung innerhalb 30 Sekunden
2. Tank leer → Nutzer erhält Warnmeldung mit Aufforderung zum
| Nachfüllen
3. Pumpe reagiert nicht → App zeigt „Pumpenfehler“
4. Manuelle Aktion → Push bestätigt erfolgreiche Ausführung
5. System offline → App meldet Verbindungsfehler

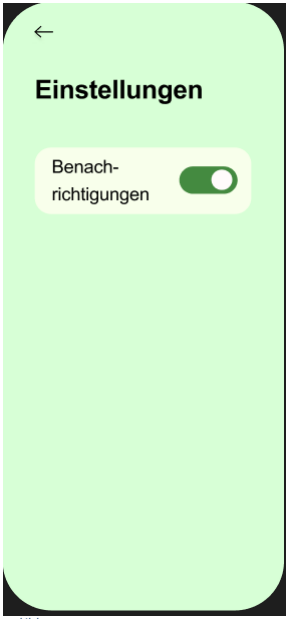
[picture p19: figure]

Abbildung 6: Benachrichtigungen aktivieren

## 6.7 Erfassung und Veröffentlichung der Bodenfeuchtigkeit

Tabelle 9: Erfassung und Veröffentlichung der Bodefeuchtigkeit
Zweck/Ziel | Automatisches Erfassen der Bodenfeuchte und Veröffentlichung per MQTT, um die aktuellen Messwerte der Pflanze für die App/Dashboard bereitzustellen.
Akteur/Auslöser | ESP und MQTT
Vorbedingung | WLAN- und MQTT-Verbindung aktiv, Sensor korrekt angeschlossen
Daten-Input | Analogsignal vom Bodenfeuchtigkeitssensor
Verarbeitungsschritte | 1. Sensorwert einlesen 2. Zeitstempel erzeugen 3. JSON-Nachricht erzeugen 4. MQTT-Nachricht an einem bestimmtenTopic senden
Ergebnis | Feuchtigkeitswert im MQTT-Broker verfügbar, App kann anzeigen
Plausibilitäten | Gültiger Wertebereich (z. B. 0–4095), ungewöhnliche Werte werden gekennzeichnet
Fehlerhandling | 0 oder ungültige Werte → als Fehler kennzeichnen MQTT offline → reconnect-Mechanismus Fallback: Retry nach Zeitintervall
Folgeprozess | Nächster Erfassungszyklus wird gestartet (z. B. alle 3 Min.)
Test Cases | - Sensor liefert gültigen Wert → MQTT publiziert
- Sensor fehlt → Fehlerstatus
- MQTT nicht erreichbar → reconnect
- JSON-Format korrekt

## 6.8 Automatische Auslösung der Bewässerung bei Trockenheit

Tabelle 10: Automatische Auslösung der Bewässerung bei Trockenheit
Zweck/Ziel | Automatische Bewässerung, wenn der Boden zu trocken ist
Akteur/Auslöser | ESP und Wasserpumpen
Vorbedingung | - Sensorwert unter Grenzwert
- Kein aktiver Sperrzeit-Timer
- Stromversorgung verfügbar
Daten-Input | Letzter Sensorwert, Schwellwert, Systemzeit
Verarbeitungsschritte | 1. Vergleich mit Schwellenwert 2. Aktivierung Relais (Pumpe) 3. Einstellbare Deaktivierungszeit 4. MQTT-Statusnachricht
Ergebnis | Pflanze wird gegossen
Plausibilitäten | Relais-Zeitfenster z. B. 10s Vermeidung von Dauerbetrieb
Fehlerhandling | Relaisausfall → Fehlerausgabe Fehlerhafte Messung → keine Auslösung Sperrzeit → automatische Blockade
Folgeprozess | Neue Sperrzeit startet System wartet auf nächsten Sensorzyklus
Test Cases | - Sensorwert unter Grenzwert → Pumpe aktiv
- Sperrzeit aktiv → keine Pumpe
- MQTT sendet Statusmeldung
- Pumpe läuft maximal x Sekunden

## 6.9 MQTT Publish – Sensor- & Statusdaten senden

Tabelle 11: MQTT Publish - Sensor- & Statusdaten senden
Zweck/Ziel | Der ESP sendet Sensorwerte und Statusmeldungen über MQTT an spezifische Topics, damit externe Systeme (App, Dashboard) Daten empfangen können.
Akteur/Auslöser | Intern: nach Messung, nach Pumpenvorgang, bei Fehlern
Berechtigung | ESP32 besitzt Publish-Rechte (MQTT-Login mit Schreibzugriff)
Vorbedingung | Aktive WLAN- & MQTT-Verbindung, gültiger Topic-Name
Daten-Input | Sensordaten, Systemstatus, Zeitstempel
Verarbeitungsschritte | 1. JSON-Nachricht erzeugen 2. Verbindung zur MQTT bestimmen. 3. Nachricht an festgelegtes Topic senden:
Ergebnis | Daten im Broker verfügbar für alle Subscriber (z. B. App)
Plausibilitäten | Nachrichten müssen gültiges JSON enthalten Topics müssen existieren bzw. zulässig sein MQTT-Verbindung muss richtig konfiguriert sein
Fehlerhandling | Kein Brokerkontakt → reconnect Fehlerhafte Daten → verworfen und geloggt
Folgeprozess | Nächster Erfassungszyklus wird gestartet (z. B. alle 3 Min.)
Test Cases | - Wert publiziert erfolgreich - JSON lesbar im MQTT-Viewer - Fehlerfall: Nachricht nicht gesendet - Reconnect funktioniert korrekt

## 6.10MQTT Subscribe – Steuerungsbefehle empfangen

Tabelle 12: MQTT Subscribe - Steuerungsbefehle empfangen
Zweck/Ziel | Der ESP empfängt Steuerbefehle (z. B. zur manuellen Pumpensteuerung) über ein MQTT-Topic und führt die gewünschten Aktionen aus.
Akteur/Auslöser | Nutzer sendet MQTT-Befehl an bestimmtes Topic
Berechtigung | MQTT-Client des ESP ist mit Leseberechtigung verbunden
Vorbedingung | WLAN- & MQTT-Verbindung aktiv, Topic korrekt abonniert
Daten-Input | MQTT-Nachricht (JSON-Datei) von ESP
Verarbeitungsschritte | 1. ESP ist Subscriber von einem bestimmten Topic 2. Nachricht wird empfangen 3. Inhalt geprüft und interpretiert 4. Pumpe aktiviert oder deaktiviert 5. Rückmeldung über Status-Topic
Ergebnis | Steuerbefehl wird ausgeführt, Status wird rückgemeldet
Plausibilitäten | Nur vordefinierte Nachricht akzeptiert (bei Pumpensteurung nur “on” und “off”)
Fehlerhandling | Ungültiger Inhalt → ignorieren & loggen Verbindungsabbruch → automatisch neuverbinden
Folgeprozess | Zustand bleibt bestehen bis neuer Befehl oder nächste automatische Aktion
Test Cases | - "on": Pumpe läuft
- "off": Pumpe stoppt
- Falscher Befehl → ignoriert
- Neuverbinden nach Trennung
- Kontrolle über App sichtbar

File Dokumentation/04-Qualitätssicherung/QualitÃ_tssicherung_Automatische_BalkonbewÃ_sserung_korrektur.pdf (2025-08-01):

### Qualitätssicherung Automatische Balkonbewässerung

© htw-Berlin | Seite 1 von 12

# Qualitätssicherung

# Automatische Balkonbewässerung

Autor: | Dzaid Abiyyu Siregar, Zul Fahmi Nur Vagala, Johannes Berg
Letzte Änderung:13. Juni 2025
Dateiname: | Qualitätssicherung_Automatische_Balkonbewässerung.docx
Version: | 0.2

## Inhaltsverzeichnis

Copyright

© Mohammad Abuosba

Die Weitergabe, Vervielfältigung oder anderweitige Nutzung dieses Dokumentes oder Teile davon ist unabhängig vom Zweck oder in welcher Form untersagt, es sei denn, die Rechteinhaber/In hat ihre ausdrückliche schriftliche Genehmigung erteilt.

Version Historie

Version: | Datum: | Verantwortlich | Änderung
0.1 | 11.11.2013 | Mohammad Abuosba | Initiale Dokumenterstellung
0.2 | 13.06.2025 | Johannes Berg | Testplan, Testfälle und Testprotokoll

Vorhandene Dokumente

Alle für die vorliegende Spezifikation ergänzenden Unterlagen müssen hier aufgeführt werden

Dokument | Autor | Datum
Automatische_Balkonbewässerung_Lastenheft | Dzaid Abiyyu Siregar, Zul Fahmi Nur Vagala, Johannes Berg | 13.06.2025
Automatische_Balkonbewässerung_Pflichtenheft Automatische_Balkonbewässerung_technische_Spezifikation.docx

## 1 Einleitung

Dieses Dokument enthält die definierten Testfälle, die sich, während Sprint 1 des Projekts zur automatisierten Pflanzenbewässerung kristallisiert haben. Ziel ist es, erste zentrale Funktionen des Systems zu überprüfen und sicherzustellen, dass die entwickelten Komponenten den Anforderungen aus dem Lasten- und Pflichtenheft, sowie der technischen Spezifikation entsprechen.
Die Testfälle decken sowohl funktionale als auch nicht-funktionale Anforderungen ab und wurden auf Basis des erarbeiteten Testplans erstellt. Sie dienen der Qualitätssicherung, dem Fehlermanagement sowie der systematischen Validierung einzelner Module und deren Zusammenspiel.
Jeder Testfall ist nach einem einheitlichen Schema dokumentiert und enthält Angaben zum Testziel, den Vorraussetzungen, dem erwarteten Verhalten sowie zu den konkreten Testdaten. Die erfolgreiche Durchführung dieser Tests bildet die Grundlage für die interne Abnahme von Sprint 1 und den Übergang in die nächste Entwicklungsphase.

### Automatische Balkonbewässerung

## Testplan

Test-Objekt | Qualitätskriterien | QS-Teststufe 1 "Source Code, Komponente, Funktion" | Bemerkungen
Test-Verfahren | Zyklus | Zuständig

### Dokumentation

App-Projekt (Flutter-Setup) | Verständlichkeit, Vollständigkeit, Richtigkeit | Editorial Review Gegenlesen | bei Abschluss der Einrichtung | Zul | Projektstruktur, Build-Konfiguration prüfen
Aufbau Testboard (ESP + Sensoren) | Korrektheit, Lesbarkeit, Eindeutigkeit | Technisches Review | Nach Aufbau | Johannes | Sauberer Aufbau für stabile Verbindung wichtig

### Applikation

Funktionalitäten

UI – Statusanzeige & Pumpe | F – Korrektheit, Aktualität | Unittest | Bei jedem UI-Update | Zul | Anzeige Verlauf und App-Navigation möglich
MQTT-Verbindung | Verbindung, Datenfluss | Integrationstest | nach Implementierung | Dzaid | Verbindung zu lokalem Broker
Sensoranbindung | F – Richtigkeit | Kalibrierung | Nach Aufbau | Dzaid | Messwert skalieren
MQTT - Publish | F – Korrektheit, Timing | Integrationstest | Nach Implementierung | Dzaid | Regelmäßige Übertragung, alle 30 sek
Pumpensteuerung | F – Richtigkeit, Timing | Modultest | Nach jeder Änderung im Code | Johannes | Sicherheitslogik beachten
Wasserverteilung / Stecksystem | F – Funktion, Durchfluss | Blackboxtest | Einmalig beim Aufbau | Johannes | Test mit einer Pumpe (+Schlauch)

### Automatische Balkonbewässerung

nicht funktionale Eigenschaften / Anforderungen

Energieverbrauch | Effizienz,
Dauerbetrieb

Datentest,
Stresstest

Täglich im
Dauerbetrieb, vor
Übergabe
Zul | Beobachtung des Stromverbrauchs möglich
Test-Objekt | Qualitätskriterien | QS-Teststufe 2 "Integration / Systemtest" | Bemerkung?
Test-Verfahren | Zyklus | Zuständig

Funktionalitäten

Sensordatenverarbeitung | F - Richtigkeit | Datentest, Lasttest, | nach jeder Änderung, am Ende | Dzaid | Messwerte mit realer Bodenfeuchte vergleichen
MQTT-Kommunikation | F – Richtigkeit, Stabilität | Performancetest, Verbindungstest | nach jeder Änderung, am Ende | Dzaid, Zul | Latenz, Verbindungsabbrüche testen
Manuelle Pumpensteuerung | F – Reaktion, Richtigkeit | Manueller Test | nach Implementierung, am Ende | Johannes, Dzaid | App-Befehl muss direkt auf Relaisausgang reagieren
Anzeige der Bodenfeuchte in UI | Usability, Verständlichkeit | Manueller Test | Vor Übergabe | Zul | Klare und aktuelle Anzeige der Feuchtigkeitswerte

nicht funktionale Eigenschaften / Anforderungen
Systemverhalten | Zuverlässigkeit, Effizienz

Lasttest,

Performancetest | Ende Sprint 1 | Dzaid, Zul,
Johannes | System muss stabil unter Dauerlast arbeiten

## 2 Testfälle

## 2.1 Sensoranbindung

Testfall | Beschreibung
Testfall-Nummer | 001
Testart | Funktionstest
Zu testender Geschäftsprozess/ Zu testende Funktionsgruppe | Feuchtigkeitssensor
Testziel | Feuchtigkeitssensoren liefern gleiche Werte bei identischen Bedingungen
Testvoraussetzungen | Feuchtigkeitssensor ist sauber, nicht beschädigt
Testfalldaten | Sensoren senden erst im trockenen und dann aus einem Wasserbehälter Werte
Erwartetes Verhalten | Jeder Sensor liefert (fast) exakt gleiche Werte. Minimale Toleranz ist gestattet (+-1%)

Testergebnis

Testergebnis | x Bestanden □ Nicht Bestanden
Fehlerkategorie | x Leicht □ Mittel □Schwer
Bemerkung | Von 5 Feuchtigkeitssensore liefern 4 fast exakt gleiche Werte (nur 3 notwendig)
Tester Kunde | Tester Auftragnehmer | Datum
| | 06.06.2025

## 2.2 MQTT-Verbindung

Testfall | Beschreibung
Testfall-Nummer | 002
Testart | Integrationstest
Zu testender Geschäftsprozess/ Zu testende Funktionsgruppe | MQTT-Kommunikation App mit Broker
Testziel | App soll stabil Nachrichten an den lokalen MQTT-Broker senden und empfangen können
Testvoraussetzungen | MQTT-Broker läuft, Netzwerkverbindung vorhanden
Testfalldaten | App verbindet sich zum Broker, sendet eine Nachricht und empfängt eine Antwort
Erwartetes Verhalten | Verbindung wird hergestellt, Nachrichten werden ohne Fehler übertragen

## 2.3 Manuelle Pumpensteuerung

Testfall | Beschreibung
Testfall-Nummer | 003
Testart | Funktionstest
Zu testender Geschäftsprozess/ Zu testende Funktionsgruppe | Steuerung der Wasserpumpe über App
Testziel | Die App aktiviert die Pumpe über ein Relaismodul bei Button-Click
Testvoraussetzungen | Relaismodul korrekt angeschlossen, App und ESP verbunden
Testfalldaten | Nutzer drückt Button in App; ESP aktiviert Relais
Erwartetes Verhalten | Pumpe schaltet sich ein und nach definierter Zeit wieder aus

## 2.4 Anzeige der Bodenfeuchte in UI

Testfall | Beschreibung
Testfall-Nummer | 004
Testart | Blackboxtest / UI - Test
Zu testender Geschäftsprozess/ Zu testende Funktionsgruppe | Visualisierung des Sensorwerts in der Benutzeroberfläche
Testziel | Nutzer soll den aktuellen Bodenfeuchtewert in der App korrekt angezeigt bekommen
Testvoraussetzungen | Sensor angeschlossen, App und ESP kommunizieren korrekt
Testfalldaten | Sensor misst Werte zwischen 0-100%
Erwartetes Verhalten | Anzeige in der App spiegelt gemessene Werte verzögerungsfrei und korrekt wieder

## 2.5 Energieverbrauch - Dauerbetrieb

Testfall | Beschreibung
Testfall-Nummer | 005
Testart | Stresstest / Langzeittest
Zu testender Geschäftsprozess/ Zu testende Funktionsgruppe | Energieaufnahme von ESP und Sensor bei Dauerbetrieb
Testziel | System darf sich nicht überhitzen oder instabil werden
Testvoraussetzungen | Dauerbetrieb über mind. 12 Stunden; Netzteil vorhanden
Testfalldaten | Betrieb mit aktivem Sensor, aktiver MQTT-Verbindung, periodischem Senden
Erwartetes Verhalten | Stromaufnahme konstant im erwarteten Bereich; kein Ausfall oder Reset

## 3 Testprotokoll

TestfallNr. | Datum | Status | Schweregrad | Datum 2. Lauf | Status 2. Lauf
001 | 06.06.2025 | bestanden | leicht
002 | 13.06.2025 | Noch nicht durchgeführt
003 | 13.06.2025 | Noch nicht durchgeführt
004 | 13.06.2025 | Noch nicht durchgeführt
005 | 13.06.2025 | Noch nicht durchgeführt

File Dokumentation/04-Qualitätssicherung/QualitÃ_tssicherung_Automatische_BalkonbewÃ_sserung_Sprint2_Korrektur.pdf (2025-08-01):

### Qualitätssicherung Automatische Balkonbewässerung

© htw-Berlin

# Qualitätssicherung_2

# Automatische Balkonbewässerung

Autor: | Dzaid Abiyyu Siregar, Zul Fahmi Nur Vagala, Johannes Berg
Letzte Änderung:13. Juni 2025
Dateiname: | Qualitätssicherung_Automatische_Balkonbewässerung2.docx
Version: | 0.2

© htw-Berlin

## Inhaltsverzeichnis

© htw-Berlin

Copyright

© Mohammad Abuosba

Die Weitergabe, Vervielfältigung oder anderweitige Nutzung dieses Dokumentes oder Teile davon ist unabhängig vom Zweck oder in welcher Form untersagt, es sei denn, die Rechteinhaber/In hat ihre ausdrückliche schriftliche Genehmigung erteilt.

Version Historie

Version: | Datum: | Verantwortlich | Änderung
0.1 | 11.11.2013 | Mohammad Abuosba | Initiale Dokumenterstellung
0.2 | 11.07.2025 | Johannes Berg | Testplan, Testfälle und Testprotokoll Sprint 2

© htw-Berlin

Vorhandene Dokumente

Alle für die vorliegende Spezifikation ergänzenden Unterlagen müssen hier aufgeführt werden

Dokument | Autor | Datum
Automatische_Balkonbewässerung_Lastenheft | Dzaid Abiyyu Siregar, Zul Fahmi Nur Vagala, Johannes Berg | 25.04.2025
Automatische_Balkonbewässerung_Pflichtenheft | | 23.05.2025
Automatische_Balkonbewässerung_technische_Spezifikation.docx | | 13.06.2025
Automatische_Balkonbewässerung_Qualitätssicherung | | 13.06.2025

© htw-Berlin

## 1 Einleitung

Dieses Dokument fasst die bestehenden sowie neu hinzugekommenen Testfälle des Projekts zur automatisierten Pflanzenbewässerung zusammen. Aufbauend auf den, während Sprint 1 definierten Testfällen, die zentrale Funktionen des Systems absichern sollten, werden in dieser Erweiterung nun auch die Testfälle aus Sprint 2 dokumentiert. Ziel ist es, die fortschreitende Systementwicklung weiterhin systematisch zu begleiten und sicherzustellen, dass sowohl neue als auch überarbeitete Komponenten den Anforderungen aus Lasten- und Pflichtenheft sowie der technischen Spezifikation entsprechen.

Die Testfälle wurden entsprechend dem bestehenden Testplan erweitert und berücksichtigen funktionale sowie nicht-funktionale Anforderungen. Sie dienen wie bisher der Qualitätssicherung, der strukturierten Fehlersuche und der Validierung des Zusammenspiels einzelner Systembestandteile. Jeder Testfall folgt einem einheitlichen Aufbau und enthält Angaben zum Testziel, den Voraussetzungen, dem erwarteten Verhalten sowie den eingesetzten Testdaten.

Durch die Ergänzung um die Testfälle aus Sprint 2 wird sichergestellt, dass neue Funktionalitäten umfassend geprüft und die kontinuierliche Weiterentwicklung des Systems abgesichert werden. Das Dokument dient somit als fortlaufendes Testprotokoll und Grundlage für weitere interne Abnahmen im Projektverlauf.

### Automatische Balkonbewässerung

© htw-Berlin | Seite 6 von 20

## 2 Testplan

## 2.1 Sprint 1

Test-Objekt | Qualitätskriterien | QS-Teststufe 1 "Source Code, Komponente, Funktion" | Bemerkungen
Test-Verfahren | Zyklus | Zuständig

### Dokumentation

App-Projekt (Flutter-Setup) | Verständlichkeit, Vollständigkeit, Richtigkeit | Editorial Review Gegenlesen | bei Abschluss der Einrichtung | Zul | Projektstruktur, Build-Konfiguration prüfen
Aufbau Testboard (ESP + Sensoren) | Korrektheit, Lesbarkeit, Eindeutigkeit | Technisches Review | Nach Aufbau | Johannes | Sauberer Aufbau für stabile Verbindung wichtig

### Applikation

Funktionalitäten

UI – Statusanzeige & Pumpe | F – Korrektheit, Aktualität | Unittest | Bei jedem UI-Update | Zul | Anzeige Verlauf und App-Navigation möglich
MQTT-Verbindung | Verbindung, Datenfluss | Integrationstest | nach Implementierung | Dzaid | Verbindung zu lokalem Broker
Sensoranbindung | F – Richtigkeit | Kalibrierung | Nach Aufbau | Dzaid | Messwert skalieren
MQTT - Publish | F – Korrektheit, Timing | Integrationstest | Nach Implementierung | Dzaid | Regelmäßige Übertragung, alle 30 sek
Pumpensteuerung | F – Richtigkeit, Timing | Modultest | Nach jeder Änderung im Code | Johannes | Sicherheitslogik beachten

### Automatische Balkonbewässerung

Wasserverteilung /
Stecksystem

F – Funktion,
Durchfluss | Blackboxtest | Einmalig beim Aufbau | Johannes | Test mit einer Pumpe (+Schlauch)

nicht funktionale Eigenschaften / Anforderungen

Energieverbrauch | Effizienz,
Dauerbetrieb | Datentest,
| Stresstest | Täglich im
| | Dauerbetrieb, vor
| | Übergabe | Zul | Beobachtung des Stromverbrauchs möglich
Test-Objekt | Qualitätskriterien | QS-Teststufe 2 "Integration / Systemtest" | Bemerkung?
Test-Verfahren | Zyklus | Zuständig

Funktionalitäten

Sensordatenverarbeitung | F - Richtigkeit | Datentest, Lasttest, | nach jeder Änderung, am Ende | Dzaid | Messwerte mit realer Bodenfeuchte vergleichen
MQTT-Kommunikation | F – Richtigkeit, Stabilität | Performancetest, Verbindungstest | nach jeder Änderung, am Ende | Dzaid, Zul | Latenz, Verbindungsabbrüche testen
Manuelle Pumpensteuerung | F – Reaktion, Richtigkeit | Manueller Test | nach Implementierung, am Ende | Johannes, Dzaid | App-Befehl muss direkt auf Relaisausgang reagieren
Anzeige der Bodenfeuchte in UI | Usability, Verständlichkeit | Manueller Test | Vor Übergabe | Zul | Klare und aktuelle Anzeige der Feuchtigkeitswerte

nicht funktionale Eigenschaften / Anforderungen
Systemverhalten | Zuverlässigkeit, Effizienz

Lasttest,

Performancetest | Ende Sprint 1 | Dzaid, Zul,
Johannes | System muss stabil unter Dauerlast arbeiten

### Automatische Balkonbewässerung

## 2.2 Sprint 2

Test-Objekt | Qualitätskriterien | QS-Teststufe 1 "Source Code, Komponente, Funktion" | Bemerkungen
Test-Verfahren | Zyklus | Zuständig

### Dokumentation

Ereignislog MQTT-Format | Korrektheit, Struktur, Vollständigkeit | Technisches Review | Nach Implementierung | Dzaid | Strukturierte JSON-Nachrichten mit definierten Feldern
Lokale Zeitplanlogik (ESP) | Vollständigkeit, Nachvollziehbarkeit | Code Review | Nach Implementierung | Dzaid | RTC-basierte Umsetzung dokumentiert
Schutzgehäuse (Skizze, Entwurf) | Eindeutigkeit, Vollständigkeit | Editorial Review | Bei Erstellung des Gehäuses | Johannes | Anforderung an Wetterschutz und Kabelführung beschrieben

### Applikation

Funktionalitäten

Zeitplan-Funktion (App) | F – Korrektheit, Bedienbarkeit | Blackboxtest, Unittest | Nach jedem UI-Update | Zul | Nutzer kann Zeiten eingeben und ändern; Validierung der Eingabe
MQTT-Sende-/Empfangsbefehl (Zeitsteuerung) | F – Korrektheit, Timing | Integrationstest | Nach Anbindung an ESP | Dzaid, Zul | Steuerbefehl wird korrekt gesendet und empfangen
MQTT-Ereignislog auf ESP | F – Struktur, Korrektheit | Modultest, JSON-Validierung | Nach jeder Änderung im Code | Dzaid | Log enthält Zeit, Aktion, Sensorwert im definierten Schema
Lokaler Zeitplan (ESP-seitig) | F – Richtigkeit, Autonomer Betrieb | Integrationstest | Nach Implementierung | Dzaid | Gießzeit wird auch ohne App-Befehl korrekt ausgeführt
Schutzgehäuse Elektronik | F – Passform, Witterungsresistenz | Funktionstest (Aufbau) | Bei Einbau | Johannes | Pumpe, ESP und Relais sicher montiert; Kabel trocken

### Automatische Balkonbewässerung

Feste Installation von
Sensoren & Pumpen

F – Stabilität,

Praxistauglichkeit | Funktionstest vor Ort | Nach Montage | Johannes | Komponenten sitzen fest im Pflanzgefäß und Wasserbehälter

nicht funktionale Eigenschaften / Anforderungen

Automatisierung | Zuverlässigkeit,
Robustheit | Langzeittest | Ende Sprint 2 | Dzaid, Johannes, Zul, (+ Anwender) | System funktioniert über längere Zeit stabil
Test-Objekt | Qualitätskriterien | QS-Teststufe 2 "Integration / Systemtest" | Bemerkung?
Test-Verfahren | Zyklus | Zuständig

Funktionalitäten

Zeitbasierte Pumpensteuerung (App->ESP) | F – Richtigkeit, Timing | Manuelle Tests | Nach Integration | Dzaid, Zul | Pumpe startet automatisch zur programmierten Zeit
MQTT-Kommunikation bei Zeitereignissen | F – Konsistenz, Stabilität | Lasttest, Integrationstest | Nach Umsetzung, regelmäßig | Dzaid, Zul | Es darf keine Konflikte bei mehreren Zeit-Ereignissen geben
Historie anzeigen | F – Aktualität | UI-Test, Review mit Nutzer | Vor Übergabe | Zul | Letztes Gießereignis, Sensorwerte und Uhrzeit korrekt sichtbar
Funktionstest: Gießen nach Zeitplan | F – Funktionalität | Gesamttest Setup | Nach Verbindung aller Komponente | Dzaid, Johannes, Zul | Pumpvorgang startet nur wenn Bedingungen erfüllt sind

nicht funktionale Eigenschaften / Anforderungen

Wetterresistenz der
Hardware | Schutz, Dauerbetrieb

Belastungstest
(Feuchtigkeit,
Außeneinsatz)
Vor Übergabe | Johannes | Geprüft bei hoher Luftfeuchte oder Außentemperatur

## 3 Testfälle

## 3.1 Sprint 1

## 3.1.1 Sensoranbindung

Testfall | Beschreibung
Testfall-Nummer | 001
Testart | Funktionstest
Zu testender Geschäftsprozess/ Zu testende Funktionsgruppe | Feuchtigkeitssensor
Testziel | Feuchtigkeitssensoren liefern gleiche Werte bei identischen Bedingungen
Testvoraussetzungen | Feuchtigkeitssensor ist sauber, nicht beschädigt
Testfalldaten | Sensoren senden erst im trockenen und dann aus einem Wasserbehälter Werte
Erwartetes Verhalten | Jeder Sensor liefert (fast) exakt gleiche Werte. Minimale Toleranz ist gestattet (+-1%)
Testergebnis | x Bestanden □ Nicht Bestanden
Fehlerkategorie | x Leicht □ Mittel □Schwer
Bemerkung | Von 5 Feuchtigkeitssensoren liefern 4 fast exakt gleiche Werte (nur 3 notwendig)
Tester Kunde | Tester Auftragnehmer | Datum
| | 06.06.2025

## 3.1.2 MQTT-Verbindung

Testfall | Beschreibung
Testfall-Nummer | 002
Testart | Integrationstest
Zu testender Geschäftsprozess/ Zu testende Funktionsgruppe | MQTT-Kommunikation App mit Broker
Testziel | App soll stabil Nachrichten an den lokalen MQTT-Broker senden und empfangen können
Testvoraussetzungen | MQTT-Broker läuft, Netzwerkverbindung vorhanden
Testfalldaten | App verbindet sich zum Broker, sendet eine Nachricht und empfängt eine Antwort
Erwartetes Verhalten | Verbindung wird hergestellt, Nachrichten werden ohne Fehler übertragen
Testergebnis | x Bestanden □ Nicht Bestanden
Fehlerkategorie | □Leicht x Mittel □Schwer

Bemerkung

Tester Kunde | Tester Auftragnehmer | Datum
| | 07.07.2025

## 3.1.3 Manuelle Pumpensteuerung

Testfall | Beschreibung
Testfall-Nummer | 003
Testart | Funktionstest
Zu testender Geschäftsprozess/ Zu testende Funktionsgruppe | Steuerung der Wasserpumpe über App
Testziel | Die App aktiviert die Pumpe über ein Relaismodul bei Button-Click
Testvoraussetzungen | Relaismodul korrekt angeschlossen, App und ESP verbunden
Testfalldaten | Nutzer drückt Button in App; ESP aktiviert Relais
Erwartetes Verhalten | Pumpe schaltet sich ein und nach definierter Zeit wieder aus
Testergebnis | x Bestanden □ Nicht Bestanden
Fehlerkategorie | □Leicht x Mittel □Schwer

Bemerkung

Tester Kunde | Tester Auftragnehmer | Datum
| | 07.07.2025

## 3.1.4 Anzeige der Bodenfeuchte in UI

Testfall | Beschreibung
Testfall-Nummer | 004
Testart | Blackboxtest / UI - Test
Zu testender Geschäftsprozess/ Zu testende Funktionsgruppe | Visualisierung des Sensorwerts in der Benutzeroberfläche
Testziel | Nutzer soll den aktuellen Bodenfeuchtewert in der App korrekt angezeigt bekommen
Testvoraussetzungen | Sensor angeschlossen, App und ESP kommunizieren korrekt
Testfalldaten | Sensor misst Werte zwischen 0-100%
Erwartetes Verhalten | Anzeige in der App spiegelt gemessene Werte verzögerungsfrei und korrekt wieder
Testergebnis | x Bestanden □ Nicht Bestanden
Fehlerkategorie | □Leicht □ Mittel x Schwer

Bemerkung

Tester Kunde | Tester Auftragnehmer | Datum
| | 05.07.2025

## 3.1.5 Energieverbrauch – Dauerbetrieb

Testfall | Beschreibung
Testfall-Nummer | 005
Testart | Stresstest / Langzeittest
Zu testender Geschäftsprozess/ Zu testende Funktionsgruppe | Energieaufnahme von ESP und Sensor bei Dauerbetrieb
Testziel | System darf sich nicht überhitzen oder instabil werden
Testvoraussetzungen | Dauerbetrieb über mind. 12 Stunden; Netzteil vorhanden
Testfalldaten | Betrieb mit aktivem Sensor, aktiver MQTT-Verbindung, periodischem Senden
Erwartetes Verhalten | Stromaufnahme konstant im erwarteten Bereich; kein Ausfall oder Reset
Testergebnis | □Bestanden □ Nicht Bestanden
Fehlerkategorie | □Leicht □ Mittel x Schwer
Bemerkung | Test kann erst nach längerem Betrieb durchgeführt werden
Tester Kunde | Tester Auftragnehmer | Datum

## 3.2 Sprint 2

## 3.2.1 Zeitplan-Funktion in der App

Testfall | Beschreibung
Testfall-Nummer | 006
Testart | Blackboxtest
Zu testender Geschäftsprozess/ Zu testende Funktionsgruppe | Zeitplanung für automatische Bewässerung
Testziel | Der Benutzer kann Zeitpunkte für das automatische Gießen definieren und speichern
Testvoraussetzungen | App ist installiert, MQTT-Verbindung zum ESP besteht
Testfalldaten | Eingabe „Bewässerung täglich um 8:00 Uhr“
Erwartetes Verhalten | Zeitplan wird gespeichert und an ESP gesendet
Testergebnis | x Bestanden □ Nicht Bestanden
Fehlerkategorie | X Leicht □ Mittel □Schwer
Bemerkung | Test kann erst nach längerem Betrieb durchgeführt werden
Tester Kunde | Tester Auftragnehmer | Datum
| | 11.07.2025

## 3.2.2 MQTT-Ereignislog

Testfall | Beschreibung
Testfall-Nummer | 007
Testart | Integrationstest
Zu testender Geschäftsprozess/ Zu testende Funktionsgruppe | MQTT-Nachrichten mit Ereignisdaten nach jeder Aktion
Testziel | ESP soll nach jeder Pumpenaktion ein korrekt formatiertes JSON-Log senden
Testvoraussetzungen | MQTT-Broker aktiv, Pumpensteuerung implementiert
Testfalldaten | Pumpenaktion auslösen, Log empfangen und prüfen
Erwartetes Verhalten | JSON-Nachricht enthält Zeitstempel, Aktion, Sensorwert
Testergebnis | x Bestanden □ Nicht Bestanden
Fehlerkategorie | □Leicht □ Mittel x Schwer
Bemerkung | Test kann erst nach längerem Betrieb durchgeführt werden
Tester Kunde | Tester Auftragnehmer | Datum
| | 11.07.2025

## 3.2.3 Lokaler Zeitplan

Testfall | Beschreibung
Testfall-Nummer | 008
Testart | Funktionstest, Logiktest
Zu testender Geschäftsprozess/ Zu testende Funktionsgruppe | Zeitvergleich auf ESP zur autonomen Pumpensteuerung
Testziel | ESP führt Bewässerung ohne App-Befehl zur eingestellten Zeit selbstständig aus
Testvoraussetzungen | RTC-Modul oder NTP-Zeitquelle vorhanden
Testfalldaten | Uhrzeit einstellen: z.B. „Gießen um 7:00 Uhr“
Erwartetes Verhalten | ESP schaltet die Pumpe automatisch um 7:00 Uhr ein
Testergebnis | x Bestanden □ Nicht Bestanden
Fehlerkategorie | □Leicht x Mittel □Schwer
Bemerkung | Test kann erst nach längerem Betrieb durchgeführt werden
Tester Kunde | Tester Auftragnehmer | Datum
| | 11.07.2025

## 3.2.4 Historie-Anzeige in der App

Testfall | Beschreibung
Testfall-Nummer | 009
Testart | UI-Test, Szenarientest
Zu testender Geschäftsprozess/ Zu testende Funktionsgruppe | Anzeige vergangener Pumpvorgänge und Sensorwerte in der App
Testziel | Nutzer sieht eine verständliche Übersicht vergangener Ereignisse
Testvoraussetzungen | Mindestens eine Pumpenaktion durchgeführt, Daten gespeichert
Testfalldaten | Nutzer öffnet Verlaufs-Ansicht
Erwartetes Verhalten | Liste zeigt Datum, Uhrzeit, Aktion (z.B. „Pumpe an“), Sensorwert
Testergebnis | x Bestanden □ Nicht Bestanden
Fehlerkategorie | □Leicht x Mittel □Schwer
Bemerkung | Test kann erst nach längerem Betrieb durchgeführt werden
Tester Kunde | Tester Auftragnehmer | Datum
| | 11.07.2025

## 3.2.5 Wettergeschütztes Gehäuse für Elektronik

Testfall | Beschreibung
Testfall-Nummer | 010
Testart | Belastungstest, Funktionstest
Zu testender Geschäftsprozess/ Zu testende Funktionsgruppe | Schutz der Elektronik gegen äußere Einflüsse (Wasser, Staub)
Testziel | ESP und Relaismodul bleiben auch bei Feuchtigkeit funktionsfähig
Testvoraussetzungen | Gehäuse ist montiert, System ist in Betrieb
Testfalldaten | System 8 Stunden lang in feuchter Umgebung betrieben (z.B. Balkon)
Erwartetes Verhalten | Keine Fehlfunktionen, stabile Verbindung
Testergebnis | □Bestanden □ Nicht Bestanden
Fehlerkategorie | □Leicht □ Mittel □Schwer
Bemerkung | Test kann erst nach längerem Betrieb durchgeführt werden
Tester Kunde | Tester Auftragnehmer | Datum

## 4 Testprotokoll

## 4.1 Sprint 1

TestfallNr. | Datum | Status | Schweregrad | Datum 2. Lauf | Status 2. Lauf
001 | 06.06.2025 | bestanden | leicht | 11.07.2025 | bestanden
002 | 07.07.2025 | bestanden | mittel | 11.07.2025 | bestanden
003 | 07.07.2025 | bestanden | mittel | 11.07.2025 | bestanden
004 | 05.07.2025 | bestanden | schwer | 11.07.2025 | bestanden
005 | 13.06.2025 | Noch nicht durchgeführt | schwer

## 4.2 Sprint 2

TestfallNr. | Datum | Status | Schweregrad | Datum 2. Lauf | Status 2. Lauf
006 | 11.07.2025 | bestanden | leicht
007 | 11.07.2025 | Bestanden (teilweise) | schwer
008 | 11.07.2025 | Bestanden (teilweise) | mittel
009 | 11.07.2025 | bestanden | mittel
010 | 11.07.2025 | Noch nicht durchgeführt | schwer

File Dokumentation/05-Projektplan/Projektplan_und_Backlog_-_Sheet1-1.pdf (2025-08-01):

Sprint Backlog

## Sprint Aufgabe Beschreibung Aufwand (h) Verantwortlich

Sprint 1 | App-Projekt aufsetzen (Flutter)

Einrichten eines Flutter-Projekts mit den notwendigen Abhängigkeiten für
MQTT-Kommunikation (z. B. mqtt_client), UI-Gerüste, und Navigation. | Zul Fahmi Nur Vagala
Sprint 1 | UI für Statusanzeige & manuelle Bewässerung

Erste Benutzeroberfläche erstellen: Anzeige des aktuellen
Bodenfeuchtigkeitswerts, sowie ein Button zur manuellen Aktivierung der
| Pumpe. | Zul Fahmi Nur Vagala
Sprint 1 | MQTT-Verbindung zur lokalen Brokeradresse (Test)
| App verbindet sich mit lokalem MQTT-Broker (z. B. Mosquitto auf PC/Handy)
| und kann Nachrichten senden & empfangen (Testumgebung). | Dzaid Abiyyu Siregar
Sprint 1 | Sensoranbindung: Bodenfeuchtesensor über ADC lesen
| ESP liest Feuchtigkeitswert über analogen Eingang (ADC) ein; Werte skalieren
| und vorbereiten für MQTT-Übertragung. | Dzaid Abiyyu Siregar

Sprint 1

MQTT-Publish des Sensorwerts an lokalen Broker (z. B. Mosquitto auf PC oder Handy zum testen) | ESP sendet den ausgelesenen Sensorwert regelmäßig (z. B. alle 30 Sek.) an den
| MQTT-Broker über ein definiertes Topic. | Dzaid Abiyyu Siregar
Sprint 1 | Steuerung der Wasserpumpe über Relaismodul
| ESP schaltet die Pumpe ein/aus, indem ein GPIO den Relaiskanal aktiviert.
| Sicherheit (max. Laufzeit, Rückmeldung) beachten. | Johannes Berg

Sprint 1

Steckverbindung und Wasserleitung provisorisch mit kleiner Pumpe testen | Erste Testinstallation mit Schläuchen, Stecksystemen und kleiner Pumpe
| durchführen, um Durchfluss zu prüfen. | Johannes Berg
Sprint 1 | ESP, Sensor und Relaismodul aufbauen (Testboard)
| Aufbau auf Breadboard (Steckplatine): saubere Verbindung zwischen ESP,
| Sensor, Relais und ggf. Debug via USB-Seriell. | Johannes Berg

Sprint 2

Zeitplan-Funktion: Eingabe eines Intervalls / Uhrzeit für Bewässerung | In der App einen Zeitplan definieren, wann automatisch gegossen werden soll.
| Wird über MQTT-Befehl an ESP gesendet. | Zul Fahmi Nur Vagala

Sprint 2

Verlauf anzeigen: Letzte Bewässerungszeit,
Feuchtigkeitswerte | App speichert letzte Aktionen und zeigt dem Benutzer eine Historie. | Zul Fahmi Nur Vagala
Sprint 2 | Benachrichtigungen testen
| Implementieren und testen, ob App Benachrichtigungen senden kann (lokal
| oder via Cloud-Dienst), z. B. bei niedrigem Feuchtigkeitswert. | Zul Fahmi Nur Vagala

Sprint 2

MQTT-Publish: Ereignislog (Zeit, Pumpenstatus, Feuchtewert) | ESP veröffentlicht nach jeder Aktion (automatisch oder manuell) eine
| strukturierte JSON-Nachricht mit Zeitstempel, Sensorwert, Aktion. | Dzaid Abiyyu Siregar
Sprint 2 | Implementierung eines lokalen Zeitplans
| Entweder mit RTC-Modul oder softwareseitig (Zeitvergleich nach NTP) wird eine
| automatische Gießzeit auf dem ESP festgelegt. | Dzaid Abiyyu Siregar

Sprint 2

Gehäuse oder wettergeschützte Box für ESP & Elektronik | Erste Schutzbox für ESP, Sensoranschluss und Relaismodul entwerfen – evtl.
| Tupperdose oder wetterfestes Plastikgehäuse verwenden. | Johannes Berg

Sprint 2

Pumpe und Sensoren im Blumentopf/Balkon dauerhaft befestigen | Sensor stabil im Pflanzgefäß verankern, Pumpe mit Wasserbehälter verbinden,
| Kabel verlegen – erster „Live-Test“ im echten Setup. | Johannes Berg
Sprint 3 | UX-Optimierung
| Verbesserung der Nutzerführung, z. B. Feedback nach Button-Klick,
| Ladeanzeigen, bessere Struktur der App-Screens. | Zul Fahmi Nur Vagala
Sprint 3 | Einstellungen für Schwellenwerte/Intervalle anpassen
| Verbesserung der Nutzerführung, z. B. Feedback nach Button-Klick,
| Ladeanzeigen, bessere Struktur der App-Screens. | Zul Fahmi Nur Vagala
Sprint 3 | MQTT Login
| Implementieren von Benutzername/Passwort für MQTT-Verbindung (bei
| Umstieg auf Cloud zwingend notwendig für Sicherheit). | Zul Fahmi Nur Vagala
Sprint 3 | Optimierung des ESP Codes
| Code aufräumen, Fehlerbehandlung verbessern, strukturierte Funktionen
| nutzen, unnötige Wiederholungen vermeiden. | Dzaid Abiyyu Siregar
Sprint 3 | Logging verbessern: Strukturierte Topics & Payloads
| Einheitliches Topic-Schema verwenden (plant1/status, plant1/sensor, …) und
| Payloads im JSON-Format mit validen Keys/Types. | Dzaid Abiyyu Siregar
Sprint 3 | Endmontage mit allen Kabeln sicher & dauerhaft
| Alle Hardware-Komponenten verlöten oder per Schraubklemme verbinden,
| wetterfest montieren, Pumpe fest fixieren. | Johannes Berg
Sprint 3 | 3D-gedrucktes Gehäuse oder wetterfeste Lösung
| Optional ein 3D-gedrucktes für draußen entwerfen oder kaufen – schützt gegen Wasser & UV-Licht. | Johannes Berg

Zeitplan & Meilensteine
Woche | Zeitraum | Sprint | Hauptaktivitäten | Meilenstein | Status
| 1 25.04. - 23.05.25 | Planung | Pflichtenheft, Backlog | M1: Pflichtenheft + Backlog | Abgeschlossen
| 3 26.05. - 01.06.25 | Sprint 1 | Grundlagen & erstes System | - | Geplant
| 4 02.06. - 08.06.25 | Sprint 1 | Grundlagen & erstes System | - | Geplant
| 5 09.06. - 13.06.25 | Sprint 1 | Grundlagen & erstes System | M2: Funktionierende App Code und ESP | Geplant
6 16.06. - 22.06.25 | Sprint 2 | Automatisierung & Konfiguration - | Geplant
7 23.06. - 29.06.25 | Sprint 2 | Automatisierung & Konfiguration - | Geplant
8 30.06. - 06.07.25 | Sprint 2 | Automatisierung & Konfiguration - | Geplant
9 07.07. - 11.07.25 | Sprint 2 | Automatisierung & Konfiguration M3: Funktionierende App und ESP Kommunikation via MQTT und fertiges Konstruktion | Geplant
| 10 14.07. - 20.07.25 | Sprint 3 | Feinschliff | - | Geplant
| 11 21.07. - 27.07.25 | Sprint 3 | Feinschliff | - | Geplant
| 12 28.07. - 01.08.25 | Sprint 3 | Feinschliff | M4: Fertiges Projekt!! | Geplant

Ressourcenplanung

### Teammitglied Rolle

Dzaid Abiyyu Siregar | ESP Coding und MQTT
Johannes Berg | Konstruktion und Tests
Zul Fahmi Nur Vagala | Handy App

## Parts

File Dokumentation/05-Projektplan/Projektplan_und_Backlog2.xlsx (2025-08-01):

Sprint Backlog
Sprint | Aufgabe | Beschreibung | Aufwand (h) | Verantwortlich
Sprint 1 | App-Projekt aufsetzen (Flutter) | Einrichten eines Flutter-Projekts mit den notwendigen Abhängigkeiten für MQTT-Kommunikation (z. B. mqtt_client), UI-Gerüste, und Navigation. | 10 | Zul Fahmi Nur Vagala
Sprint 1 | UI für Statusanzeige & manuelle Bewässerung | Erste Benutzeroberfläche erstellen: Anzeige des aktuellen Bodenfeuchtigkeitswerts, sowie ein Button zur manuellen Aktivierung der Pumpe. | 5 | Zul Fahmi Nur Vagala
Sprint 1 | MQTT-Verbindung zur lokalen Brokeradresse (Test) | App verbindet sich mit lokalem MQTT-Broker (z. B. Mosquitto auf PC/Handy) und kann Nachrichten senden & empfangen (Testumgebung). | 1 | Dzaid Abiyyu Siregar
Sprint 1 | Sensoranbindung: Bodenfeuchtesensor über ADC lesen | ESP liest Feuchtigkeitswert über analogen Eingang (ADC) ein; Werte skalieren und vorbereiten für MQTT-Übertragung. | 5 | Dzaid Abiyyu Siregar
Sprint 1 | MQTT-Publish des Sensorwerts an lokalen Broker (z. B. Mosquitto auf PC oder Handy zum testen) | ESP sendet den ausgelesenen Sensorwert regelmäßig (z. B. alle 30 Sek.) an den MQTT-Broker über ein definiertes Topic. | 2 | Dzaid Abiyyu Siregar
Sprint 1 | Steuerung der Wasserpumpe über Relaismodul | ESP schaltet die Pumpe ein/aus, indem ein GPIO den Relaiskanal aktiviert. Sicherheit (max. Laufzeit, Rückmeldung) beachten. | 10 | Johannes Berg
Sprint 1 | Steckverbindung und Wasserleitung provisorisch mit kleiner Pumpe testen | Erste Testinstallation mit Schläuchen, Stecksystemen und kleiner Pumpe durchführen, um Durchfluss zu prüfen. | 2 | Johannes Berg
Sprint 1 | ESP, Sensor und Relaismodul aufbauen (Testboard) | Aufbau auf Breadboard (Steckplatine): saubere Verbindung zwischen ESP, Sensor, Relais und ggf. Debug via USB-Seriell. | 2 | Johannes Berg
Sprint 2 | Zeitplan-Funktion: Eingabe eines Intervalls / Uhrzeit für Bewässerung | In der App einen Zeitplan definieren, wann automatisch gegossen werden soll. Wird über MQTT-Befehl an ESP gesendet. | 5 | Zul Fahmi Nur Vagala
Sprint 2 | Verlauf anzeigen: Letzte Bewässerungszeit, Feuchtigkeitswerte | App speichert letzte Aktionen und zeigt dem Benutzer eine Historie. | 5 | Zul Fahmi Nur Vagala
Sprint 2 | Benachrichtigungen testen | Implementieren und testen, ob App Benachrichtigungen senden kann (lokal oder via Cloud-Dienst), z. B. bei niedrigem Feuchtigkeitswert. | 1 | Zul Fahmi Nur Vagala
Sprint 2 | MQTT-Publish: Ereignislog (Zeit, Pumpenstatus, Feuchtewert) | ESP veröffentlicht nach jeder Aktion (automatisch oder manuell) eine strukturierte JSON-Nachricht mit Zeitstempel, Sensorwert, Aktion. | 10 | Dzaid Abiyyu Siregar
Sprint 2 | Implementierung eines lokalen Zeitplans | Automatische Gießzeit auf dem ESP festgelegt. | 5 | Dzaid Abiyyu Siregar
Sprint 2 | Gehäuse oder wettergeschützte Box für ESP & Elektronik | Erste Schutzbox für ESP, Sensoranschluss und Relaismodul entwerfen – evtl. Tupperdose oder wetterfestes Plastikgehäuse verwenden. | 5 | Johannes Berg
Sprint 2 | Pumpe und Sensoren im Blumentopf/Balkon dauerhaft befestigen | Sensor stabil im Pflanzgefäß verankern, Pumpe mit Wasserbehälter verbinden, Kabel verlegen – erster „Live-Test“ im echten Setup. | 10 | Johannes Berg
Sprint 3 | UX-Optimierung | Verbesserung der Nutzerführung, z. B. Feedback nach Button-Klick, Ladeanzeigen, bessere Struktur der App-Screens. | 5 | Zul Fahmi Nur Vagala
Sprint 3 | Einstellungen für Schwellenwerte/Intervalle anpassen | Verbesserung der Nutzerführung, z. B. Feedback nach Button-Klick, Ladeanzeigen, bessere Struktur der App-Screens. | 5 | Zul Fahmi Nur Vagala
Sprint 3 | MQTT Login | Implementieren von Benutzername/Passwort für MQTT-Verbindung (bei Umstieg auf Cloud zwingend notwendig für Sicherheit). | 5 | Zul Fahmi Nur Vagala
Sprint 3 | Optimierung des ESP Codes | Code aufräumen, Fehlerbehandlung verbessern, strukturierte Funktionen nutzen, unnötige Wiederholungen vermeiden. | 5 | Dzaid Abiyyu Siregar
Sprint 3 | Logging verbessern: Strukturierte Topics & Payloads | Einheitliches Topic-Schema verwenden (plant1/status, plant1/sensor, …) und Payloads im JSON-Format mit validen Keys/Types. | 10 | Dzaid Abiyyu Siregar
Sprint 3 | ESP, Power Supply einbauen | Optisch schön Geräte im Pflanzenkasten verstauen | 5 | Johannes Berg
Sprint 3 | 3D-gedrucktes Gehäuse oder wetterfeste Lösung | Wetterfestes Abteil im Pflanzenkasten mit Klappe, um Zugang zu ESP zu bekommen | 10 | Johannes Berg
Sprint 3 | App bedienfreundlicher gestalten | z.B. In App Sensor1,2,3 ändern zu [Pflanzenname] oder Kunde kann sich selbst aussuchen | 10 | Zul Fahmi Nur Vagala
Sprint 3 | Löcher für Schläuche bohren | Löcher im oberen Bereich des Kastens für Wasserzufuhr | 5 | Johannes Berg
Sprint 3 | Lösung bei Internetausfall | MQTT benötigt Netzwerkverbindung, Alternative gebraucht | 10 | Dzaid Abiyyu Siregar
Zeitplan & Meilensteine
Woche | Zeitraum | Sprint | Hauptaktivitäten | Meilenstein | Status
1 | 25.04. - 23.05.25 | Planung | Pflichtenheft, Backlog | M1: Pflichtenheft + Backlog | Abgeschlossen
3 | 26.05. - 01.06.25 | Sprint 1 | Grundlagen & erstes System | - | Geplant
4 | 02.06. - 08.06.25 | Sprint 1 | Grundlagen & erstes System | - | Geplant
5 | 09.06. - 13.06.25 | Sprint 1 | Grundlagen & erstes System | M2: Funktionierende App Code und ESP | Geplant
6 | 16.06. - 22.06.25 | Sprint 2 | Automatisierung & Konfiguration | - | Geplant
7 | 23.06. - 29.06.25 | Sprint 2 | Automatisierung & Konfiguration | - | Geplant
8 | 30.06. - 06.07.25 | Sprint 2 | Automatisierung & Konfiguration | - | Geplant
9 | 07.07. - 11.07.25 | Sprint 2 | Automatisierung & Konfiguration | M3: Funktionierende App und ESP Kommunikation via MQTT und fertiges Konstruktion | Geplant
10 | 14.07. - 20.07.25 | Sprint 3 | Feinschliff | - | Geplant
11 | 21.07. - 27.07.25 | Sprint 3 | Feinschliff | - | Geplant
12 | 28.07. - 01.08.25 | Sprint 3 | Feinschliff | M4: Fertiges Projekt!! | Geplant
Ressourcenplanung
Teammitglied | Rolle
Dzaid Abiyyu Siregar | ESP Coding und MQTT
Johannes Berg | Konstruktion, Hardware und Tests
Zul Fahmi Nur Vagala | Handy App

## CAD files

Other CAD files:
Konstruktion/baugruppen/konstruktionsprint1.dwg
Konstruktion/baugruppen/konstruktionsprint1.iam
Konstruktion/bauteile/sprint1/beetkasten.ipt
Konstruktion/bauteile/sprint1/espverkleidung.ipt
Konstruktion/bauteile/sprint1/wassertank.ipt
Konstruktion/bauteile/sprint3/deckel.ipt
Konstruktion/bauteile/sprint3/trennwand.ipt

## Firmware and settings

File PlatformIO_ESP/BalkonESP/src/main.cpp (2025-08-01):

#include <Arduino.h>
#include <WiFi.h>
#include <WiFiClientSecure.h>
#include <PubSubClient.h>
#include <Preferences.h>
#include <ArduinoJson.h>

// WiFi credentials
const char* ssid = "Pixel 6";
const char* password = "namasaya";

// MQTT broker info (HiveMQ Cloud)
const char* mqttServer = "cd5a01681d434871ab7952c6e6b0252d.s1.eu.hivemq.cloud";
const int mqttPort = 8883;
const char* mqttUser = "dzaid";
const char* mqttPassword = "Ffsnoway1!";
const char* mqttPubTopic = "pflanzen/pflanze01";
const char* mqttSubTopic = "pflanzen/pflanze01/control";

// TLS Root Certificate
const char* root_ca = \
"-----BEGIN CERTIFICATE-----\n" \
"MIIFazCCA1OgAwIBAgIRAIIQz7DSQONZRGPgu2OCiwAwDQYJKoZIhvcNAQELBQAw\n" \
"TzELMAkGA1UEBhMCVVMxKTAnBgNVBAoTIEludGVybmV0IFNlY3VyaXR5IFJlc2Vh\n" \
"cmNoIEdyb3VwMRUwEwYDVQQDEwxJU1JHIFJvb3QgWDEwHhcNMTUwNjA0MTEwNDM4\n" \
"WhcNMzUwNjA0MTEwNDM4WjBPMQswCQYDVQQGEwJVUzEpMCcGA1UEChMgSW50ZXJu\n" \
"ZXQgU2VjdXJpdHkgUmVzZWFyY2ggR3JvdXAxFTATBgNVBAMTDElTUkcgUm9vdCBY\n" \
"MTCCAiIwDQYJKoZIhvcNAQEBBQADggIPADCCAgoCggIBAK3oJHP0FDfzm54rVygc\n" \
"h77ct984kIxuPOZXoHj3dcKi/vVqbvYATyjb3miGbESTtrFj/RQSa78f0uoxmyF+\n" \
"0TM8ukj13Xnfs7j/EvEhmkvBioZxaUpmZmyPfjxwv60pIgbz5MDmgK7iS4+3mX6U\n" \
"A5/TR5d8mUgjU+g4rk8Kb4Mu0UlXjIB0ttov0DiNewNwIRt18jA8+o+u3dpjq+sW\n" \
"T8KOEUt+zwvo/7V3LvSye0rgTBIlDHCNAymg4VMk7BPZ7hm/ELNKjD+Jo2FR3qyH\n" \
"B5T0Y3HsLuJvW5iB4YlcNHlsdu87kGJ55tukmi8mxdAQ4Q7e2RCOFvu396j3x+UC\n" \
"B5iPNgiV5+I3lg02dZ77DnKxHZu8A/lJBdiB3QW0KtZB6awBdpUKD9jf1b0SHzUv\n" \
"KBds0pjBqAlkd25HN7rOrFleaJ1/ctaJxQZBKT5ZPt0m9STJEadao0xAH0ahmbWn\n" \
"OlFuhjuefXKnEgV4We0+UXgVCwOPjdAvBbI+e0ocS3MFEvzG6uBQE3xDk3SzynTn\n" \
"jh8BCNAw1FtxNrQHusEwMFxIt4I7mKZ9YIqioymCzLq9gwQbooMDQaHWBfEbwrbw\n" \
"qHyGO0aoSCqI3Haadr8faqU9GY/rOPNk3sgrDQoo//fb4hVC1CLQJ13hef4Y53CI\n" \
"rU7m2Ys6xt0nUW7/vGT1M0NPAgMBAAGjQjBAMA4GA1UdDwEB/wQEAwIBBjAPBgNV\n" \
"HRMBAf8EBTADAQH/MB0GA1UdDgQWBBR5tFnme7bl5AFzgAiIyBpY9umbbjANBgkq\n" \
"hkiG9w0BAQsFAAOCAgEAVR9YqbyyqFDQDLHYGmkgJykIrGF1XIpu+ILlaS/V9lZL\n" \
"ubhzEFnTIZd+50xx+7LSYK05qAvqFyFWhfFQDlnrzuBZ6brJFe+GnY+EgPbk6ZGQ\n" \
"3BebYhtF8GaV0nxvwuo77x/Py9auJ/GpsMiu/X1+mvoiBOv/2X/qkSsisRcOj/KK\n" \
"NFtY2PwByVS5uCbMiogziUwthDyC3+6WVwW6LLv3xLfHTjuCvjHIInNzktHCgKQ5\n" \
"ORAzI4JMPJ+GslWYHb4phowim57iaztXOoJwTdwJx4nLCgdNbOhdjsnvzqvHu7Ur\n" \
"TkXWStAmzOVyyghqpZXjFaH3pO3JLF+l+/+sKAIuvtd7u+Nxe5AW0wdeRlN8NwdC\n" \
"jNPElpzVmbUq4JUagEiuTDkHzsxHpFKVK7q4+63SM1N95R1NbdWhscdCb+ZAJzVc\n" \
"oyi3B43njTOQ5yOf+1CceWxG1bQVs5ZufpsMljq4Ui0/1lvh+wjChP4kqKOJ2qxq\n" \
"4RgqsahDYVvTH9w7jXbyLeiNdd8XM2w9U/t7y0Ff/9yi0GE44Za4rF2LN9d11TPA\n" \
"mRGunUHBcnWEvgJBQl9nJEiU0Zsnvgc/ubhPgXRR4Xq37Z0j4r7g1SgEEzwxA57d\n" \
"emyPxgcYxn/eR44/KJ4EBs+lVDR3veyJm+kXQ99b21/+jh5Xos1AnX5iItreGCc=\n" \
"-----END CERTIFICATE-----";

// Pins
const int moisturePins[4] = {35, 32, 33, 34};
const int pumpPins[3] = {25, 26, 27};

// Timing
const unsigned long publishInterval = 60000; // 60 seconds
unsigned long lastPublishTime = 0;
const unsigned long calibrationPeriod = 20000;

// Pump control timing
unsigned long customPumpDuration = 15000; // default: 15s
unsigned long pumpStartTimes[3] = {0, 0, 0};  // Track when each pump was turned on
bool pumpActive[3] = {false, false, false};  // Track pump state

// Preferences
Preferences preferences;
int airValues[4];
int waterValues[4];
unsigned long startTime;
bool isCalibrated;

// WiFi & MQTT
WiFiClientSecure secureClient;
PubSubClient client(secureClient);

// Function declarations
void setup_wifi();
void reconnect();
void publishSensorData();
void mqttCallback(char* topic, byte* payload, unsigned int length);

void setup() {
  Serial.begin(115200);

  for (int i = 0; i < 3; i++) {
    pinMode(pumpPins[i], OUTPUT);
    digitalWrite(pumpPins[i], LOW);
  }

  preferences.begin("moisture", false);

  isCalibrated = preferences.getBool("isCalibrated", false);
  for (int i = 0; i < 4; i++) {
    airValues[i] = preferences.getInt(("air" + String(i)).c_str(), 4095);
    waterValues[i] = preferences.getInt(("water" + String(i)).c_str(), 0);
  }

  if (!isCalibrated) {
    Serial.println("Calibration mode: insert sensors into dry/wet soil alternately.");
    startTime = millis();
  } else {
    Serial.println("Loaded calibration values.");
  }

  setup_wifi();

  secureClient.setCACert(root_ca);
  client.setServer(mqttServer, mqttPort);
  client.setCallback(mqttCallback);
}

void loop() {
  if (!client.connected()) {
    reconnect();
  }
  client.loop();

  // Auto-calibration logic
  if (!isCalibrated && millis() - startTime < calibrationPeriod) {
    for (int i = 0; i < 4; i++) {
      int value = analogRead(moisturePins[i]);
      waterValues[i] = min(waterValues[i], value);
      airValues[i] = max(airValues[i], value);
    }
    Serial.println("Calibrating...");
  } else if (!isCalibrated) {
    for (int i = 0; i < 4; i++) {
      preferences.putInt(("air" + String(i)).c_str(), airValues[i]);
      preferences.putInt(("water" + String(i)).c_str(), waterValues[i]);
    }
    preferences.putBool("isCalibrated", true);
    isCalibrated = true;
    Serial.println("Calibration complete.");
  }

  // Periodic data publish
  if (millis() - lastPublishTime >= publishInterval && isCalibrated) {
    publishSensorData();
    lastPublishTime = millis();
  }
  // Pump autoshutoff
  for (int i = 0; i < 3; i++) {
  if (pumpActive[i] && millis() - pumpStartTimes[i] >= customPumpDuration) {
    digitalWrite(pumpPins[i], LOW);
    pumpActive[i] = false;
    Serial.printf("Pump %d OFF (timer ended)\n", i + 1);
  }
}

}

void publishSensorData() {
  StaticJsonDocument<200> doc;

  for (int i = 0; i < 4; i++) {
    int value = analogRead(moisturePins[i]);
    int percent = map(value, airValues[i], waterValues[i], 0, 100);
    percent = constrain(percent, 0, 100);

    doc["sensor" + String(i + 1)] = percent;

    Serial.printf("Sensor %d: %d%% (Raw: %d)\n", i + 1, percent, value);
  }

  char buffer[256];
  size_t len = serializeJson(doc, buffer);
  client.publish(mqttPubTopic, buffer, len);
}

void mqttCallback(char* topic, byte* payload, unsigned int length) {
  Serial.print("Message arrived [");
  Serial.print(topic);
  Serial.print("] ");

  // Convert payload to string
  String json;
  for (unsigned int i = 0; i < length; i++) {
    json += (char)payload[i];
  }
  Serial.println(json);

  // Parse JSON
  StaticJsonDocument<256> doc;
  DeserializationError error = deserializeJson(doc, json);
  if (error) {
    Serial.print("JSON parsing failed: ");
    Serial.println(error.c_str());
    return;
  }

  // Safe pump control
  if (doc.containsKey("pump") && doc["pump"].is<JsonArray>()) {
  JsonArray pumpArray = doc["pump"].as<JsonArray>();
  
  unsigned long incomingDuration = customPumpDuration; // fallback default
  if (doc.containsKey("duration")) {
    unsigned long parsed = doc["duration"].as<unsigned long>();
    if (parsed >= 5000 && parsed <= 60000) {
      incomingDuration = parsed;
      Serial.printf("✅ Custom watering duration received: %lu ms\n", incomingDuration);
    } else {
      Serial.println("⚠️ Invalid watering duration. Using default.");
    }
  }

  for (int i = 0; i < 3; i++) {
    bool state = false;

    if (i < pumpArray.size()) {
      JsonVariant element = pumpArray[i];
      if (element.is<bool>()) {
        state = element.as<bool>();
      } else {
        Serial.printf("Pump %d: Invalid type\n", i + 1);
      }
    } else {
      Serial.printf("Pump %d: No value in array\n", i + 1);
    }

    digitalWrite(pumpPins[i], state ? HIGH : LOW);
    pumpActive[i] = state;

    if (state) {
      pumpStartTimes[i] = millis();
      // Store per-pump duration as needed (or keep global if shared)
      Serial.printf("🚿 Pump %d ON for %lu ms\n", i + 1, incomingDuration);
    } else {
      Serial.printf("⛔ Pump %d OFF\n", i + 1);
    }
  }

  // Finally, store the incoming duration globally if desired
  customPumpDuration = incomingDuration;

  } else {
    Serial.println("Invalid or missing 'pump' array in MQTT message.");
  }
}




void setup_wifi() {
  Serial.println("Connecting to WiFi...");
  WiFi.begin(ssid, password);

  while (WiFi.status() != WL_CONNECTED) {
    delay(500);
    Serial.print(".");
  }

  Serial.println("\nWiFi connected. IP address: " + WiFi.localIP().toString());
}

void reconnect() {
  while (!client.connected()) {
    Serial.print("Connecting to MQTT... ");
    if (client.connect("esp32Client", mqttUser, mqttPassword)) {
      Serial.println("connected.");
      client.subscribe(mqttSubTopic);
      Serial.printf("Subscribed to %s\n", mqttSubTopic);
    } else {
      Serial.print("Failed (rc=");
      Serial.print(client.state());
      Serial.println("). Retrying in 5 seconds...");
      delay(5000);
    }
  }
}

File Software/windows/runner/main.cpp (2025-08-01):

#include <flutter/dart_project.h>
#include <flutter/flutter_view_controller.h>
#include <windows.h>

#include "flutter_window.h"
#include "utils.h"

int APIENTRY wWinMain(_In_ HINSTANCE instance, _In_opt_ HINSTANCE prev,
                      _In_ wchar_t *command_line, _In_ int show_command) {
  // Attach to console when present (e.g., 'flutter run') or create a
  // new console when running with a debugger.
  if (!::AttachConsole(ATTACH_PARENT_PROCESS) && ::IsDebuggerPresent()) {
    CreateAndAttachConsole();
  }

  // Initialize COM, so that it is available for use in the library and/or
  // plugins.
  ::CoInitializeEx(nullptr, COINIT_APARTMENTTHREADED);

  flutter::DartProject project(L"data");

  std::vector<std::string> command_line_arguments =
      GetCommandLineArguments();

  project.set_dart_entrypoint_arguments(std::move(command_line_arguments));

  FlutterWindow window(project);
  Win32Window::Point origin(10, 10);
  Win32Window::Size size(1280, 720);
  if (!window.Create(L"bewaesserung_mobile_app", origin, size)) {
    return EXIT_FAILURE;
  }
  window.SetQuitOnClose(true);

  ::MSG msg;
  while (::GetMessage(&msg, nullptr, 0, 0)) {
    ::TranslateMessage(&msg);
    ::DispatchMessage(&msg);
  }

  ::CoUninitialize();
  return EXIT_SUCCESS;
}

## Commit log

2025-06-06 Menü-Drawer erstellt, Clicked-Reaction-Funktion für jede Optionen erstellt und Slide-Funktion bei Informationen für jede Sensoren erstellt
    Former-commit-id: 66dd714080296f14e1cb8d64073ed1007d3b84e9
2025-06-11 Zeitplan-Display mit Funktionen (toggle-button zur Aktivierung der automatischen Bewässerung und Zahlen-Input für die Uhrzeit) in zeitplan.dart erstellt
    Former-commit-id: 75456e91ed0e93ee1bb25d5fd43c9ec33f0f636e
2025-06-11 Ios- und Android-build bei Debugging aktualisiert
    Former-commit-id: fceca9504bbf61cb6016d0b333e60b5a8a67dc30
2025-06-13 Upload New File
    Former-commit-id: 286e796e55a075a4ae7db4794047a6c3fc561e99
    [konstruktionsprint1.iam]
2025-06-13 Upload New File
    Former-commit-id: 8666d7b2b66333323f636d97a37fe8a9ce892712
    [konstruktionsprint1.dwg]
2025-06-13 Upload New File
    Former-commit-id: d5d83509aba0662a505f5fc91bde0bed5e5baa75
    [beetkasten.ipt]
2025-06-13 Upload New File
    Former-commit-id: 496bfbab587b1a0e55416c628928d7864df735ae
    [espverkleidung.ipt]
2025-06-13 Upload New File
    Former-commit-id: 34df06a82e62302c2b113fd3591756d098b14188
    [wassertank.ipt]
2025-06-27 Änderung der Pop-Up-Animation für jede Box jeder Tage
    Former-commit-id: 431049c4968bd60daedb8e654f792cad245dea93
2025-06-27 das Datum dynamisch anhand des aktuellen Tages anzeigen
    Former-commit-id: c05bcb01097d9d644ea145537c624123343d02e3
2025-07-02 Add haptic feedback on 'Jetzt bewässern' button
    Former-commit-id: f68607ae147e503fd77fd57a7a0c883653faf441
2025-07-02 tested "Jetzt bewässern" → send MQTT message
    Former-commit-id: 1aa066d21a279829d11405fb621c11e3f0efeee3
2025-07-02 Current day entries: shown directly as a list Previous 6 days: shown as boxes Tap a box ➜ see a popup with that day’s entries
    Former-commit-id: 57109d137b71b383d7d5d5853692a3933d2993c4
2025-07-04 added a “Show Password” toggle
    Former-commit-id: 4baab1d798fad92613e4272c55f2688ef3a75d97
2025-07-09 added the 🔐 icon beside the “MQTT Verbindung” heading, and make it clickable to autofill the saved credentials
    Former-commit-id: 8d7fea44c20519734fdae9d004d98f5428766a4e
2025-07-09 A "Jetzt bewässern" button to trigger all 3 pumps and individual buttons for each sensor to water just that one
    Former-commit-id: d6922416eecfb2f92102c8efa43b57e2f6c146f2
2025-07-11 added push notification when automatic watering, low soil moisture (≤ 20%), low water level (≤ 20%)
    Former-commit-id: 4161d26e7bd8e2728b6816b39b8b193fc6311ccf
2025-07-11 Added MQTT disconnec button, broker link, notifications toggle default, and plugin updates
    Former-commit-id: aa4176ac7f74e3af9b833c4560b7907b7fe23913
2025-07-11 fix bugs on android devices
    Former-commit-id: 780de0b42be54ef1548b8d3a1021f1e3449ceec3
2025-07-11 Upload New File for Hannes to edit
    Former-commit-id: 7674c38bb11f91f75e7acb0a62c251e8c7a83fc1
    [Projektplan_und_Backlog.xlsx]
2025-07-11 Upload New File
    Former-commit-id: d9f56e993b2274c195d55d677a1e8df3e703a442
    [Projektplan_und_Backlog2.xlsx]
2025-07-20 change the toggle like the notification toggle button
    Former-commit-id: 903bf397e737643c0a192407f2743f1daac6f7a6
2025-07-20 fixed all toggle button when light mode is on
    Former-commit-id: 052a825094f08eca85029e55935f51c538e53593
2025-07-25 by all sensors changed into all plants on VerlaufScreen
    Former-commit-id: 040d3e33b88319ab56e9423d9a5de3b7c17b3f1a
2025-07-29 add animation for watering on a single plant button
    Former-commit-id: 56546875f457c46ed6039ed4e32d11ba77816e2e
2025-07-29 added animation on alle pflanzen manuell bewässern button
    Former-commit-id: 092abdca232d280f345887bec4bb24843ecc06e5
2025-07-30 corrected Sensor to percent Calculation, RESET TO RECALIBRATE
    Former-commit-id: 12ed4edba467d6aa144cae55ec2e120852812496
    [main.cpp]
2025-07-30 updated readme (what to do if sensor doesnt display correct percentage)
    Former-commit-id: c27cf1da3872773ce79b7d460734beee3f413566
2025-07-31 add Alert for sudden moisture drop and spesific notif on each sensor when reach 20%, 10% and 0%
    Former-commit-id: 574d06761dfe9542977fbed171dac0015a313862
2025-07-31 fixed bug when pushed bewässern button for a single plant
    Former-commit-id: 4049e4023433ff6be1f287437f959b5693d0a476
2025-08-01 load the last time watered on letzte Bewässerung after restarting and changed button size width on bewässern button for each palnts
    Former-commit-id: cf871a272f2a0f2ff9f6c0a218366e240d57f45a
2025-08-01 Upload New File
    Former-commit-id: ae1e992e077966626e76a4327bb921bcf33050b7
    [deckel.ipt]
2025-08-01 Upload New File
    Former-commit-id: ef2fe7099e492caef349da010d9eb0475afec129
    [trennwand.ipt]
2025-08-01 Initial project commit
    [Projektplan_und_Backlog.xlsx, Projektplan_und_Backlog2.xlsx, beetkasten.ipt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]
